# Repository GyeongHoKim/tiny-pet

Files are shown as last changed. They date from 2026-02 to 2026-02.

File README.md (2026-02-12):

# Tiny Pet

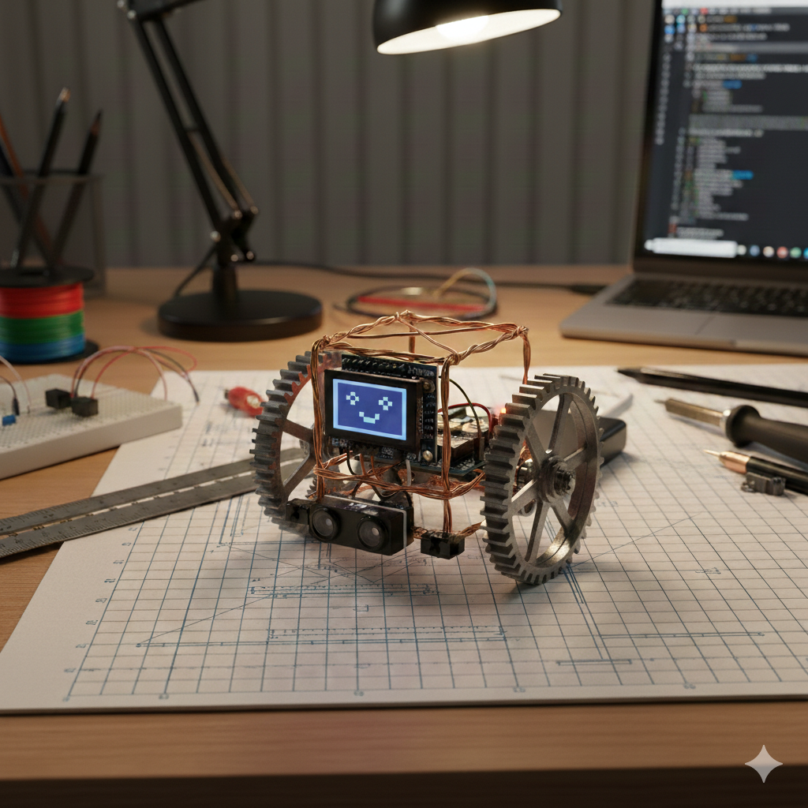
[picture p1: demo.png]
Demo


Small desk pet robot (TinyGo): random movement, obstacle avoidance (ultrasonic), edge avoidance (IR), OLED face expressions. Runs on Arduino Uno/Nano or STM32 Blue Pill.

## Requirements

- **Board:** Arduino Uno (`arduino`), Arduino Nano (`arduino-nano`), or STM32 Blue Pill (`bluepill`). Arduino: 5 V logic. Blue Pill: 3.3 V logic.
- **Software:** Go 1.20+, [TinyGo](https://tinygo.org/getting-started/install/). For Arduino: avrdude (used by TinyGo flash). For Blue Pill: [OpenOCD](http://openocd.org/) and ST-Link v2 programmer.

## Features

- **Random movement** — Drives forward and occasionally turns at random to wander on a flat surface.
- **Obstacle avoidance** — Ultrasonic sensor (HC-SR04) detects obstacles ahead; robot stops, reverses, then turns away. Threshold: `OBSTACLE_DISTANCE_THRESHOLD` in `sensors.go`.
- **Edge detection** — Two front IR sensors (A1–A2) detect desk edges; robot stops, reverses, and turns to avoid falling. Threshold: `EDGE_DETECTION_THRESHOLD` in `sensors.go`.
- **OLED face** — SSD1306 128x64 I2C OLED shows expressive faces: happy (moving), surprised (obstacle), scared (edge), excited (interacting), neutral (idle), with periodic blink animation.
- **Interaction (optional)** — Status LED (D13) and buzzer (D8) indicate current state (moving, avoiding obstacle, avoiding edge). Calibration on startup is indicated by LED blinks and beeps.

## Parts list

### Board

| Item | Note |
| --- | --- |
| Arduino Uno or Arduino Nano | Uno: target `arduino`. Nano: target `arduino-nano`. 5 V. |
| STM32 Blue Pill (STM32F103C8) | Target `bluepill`. 3.3 V. Low-cost option; requires ST-Link v2 to flash. |

### Required

| Component | Qty | Spec |
| --- | --- | --- |
| Mini L298N motor driver | 1 | H-bridge, 4 logic pins (IN1–IN4). ENA/ENB jumper → HIGH. Motor power from separate supply. |
| DC gear motors | 2 | 3–6 V DC gear motor (17–68 RPM range). |
| Steel gear 65T (wheels) | 2 | Press-fit on motor shaft, acts as wheel. |
| Copper wire frame | — | 1 mm (structural) + 0.7 mm (detail). Forms the body/chassis. |
| Ultrasonic distance sensor | 1 | HC-SR04 or compatible. Trig + Echo (digital). |
| IR sensors (analog) | 2 | Analog output to A1–A2 (front). Lower ADC = edge (e.g. TCRT5000-style). |
| SSD1306 OLED display | 1 | I2C (addr 0x3C). A4 (SDA), A5 (SCL). See **Recommended display** below. |
| Power supply (USB/adapter) | 1 | 5 V for Uno/Nano (USB or regulated adapter). Alternative: battery stack below. |
| 3.7V Li-ion battery (1S) | 1 | For battery operation (desk roaming). e.g. 18650, 14500, or pouch. |
| 1S protection module | 1 | Use with battery. Over-discharge/overcharge/short protection (B+/B-/P+/P-). |
| 5V boost converter | 1 | 3.x V → 5V (e.g. MT3608). Input/output capacitors recommended. |
| 5V→3.3V LDO (optional) | 1 | For Blue Pill or 3.3V peripherals (e.g. AMS1117-3.3). |

### Optional

| Component | Pin in code |
| --- | --- |
| Status LED | D13 (often built-in) |
| Buzzer | D8 (other leg GND) |
| MPU6050 (I2C) | SDA, SCL |
| Button | Free digital pin (not in current code) |

### Recommended display (fits 2KB SRAM)

**Use a 128×32 I2C OLED.** Firmware uses a 512-byte buffer; the face fills the screen.

| Product | Spec | Note |
| --- | --- | --- |
| [Adafruit 4440 – Monochrome 0.91" 128×32 I2C OLED](https://www.adafruit.com/product/4440) | 128×32, I2C 0x3C | STEMMA QT / Qwiic; 4-pin. ~$12.50. |
| Generic 0.91" 128×32 SSD1306 I2C | 128×32, I2C 0x3C | Many clones; ensure I2C (not SPI). |

We support Uno/Nano (2KB SRAM) only. If you use a 128×64 OLED on them, the face is drawn in the **top half** only.

## Wiring (Arduino pins)

```
D5, D4  → Mini L298N IN1, IN2 (left motor).  H-bridge: fwd/rev/stop.
D6, D9  → Mini L298N IN3, IN4 (right motor). ENA/ENB jumper → HIGH.
D7, A0  → Ultrasonic Trig, Echo (HC-SR04)
A1–A2   → IR edge sensors (analog, front only). Lower ADC = edge.
A4, A5  → SSD1306 OLED (I2C SDA, SCL). Hardware I2C on ATmega328P.
D13, D8 → Optional: LED, Buzzer
```

Pin constants: `hardware_arduino.go` (Uno/Nano) or `hardware_bluepill.go` (Blue Pill). Thresholds: `sensors.go` / `sensors_bluepill.go` (`OBSTACLE_DISTANCE_THRESHOLD`, `EDGE_DETECTION_THRESHOLD`).

## Wiring (STM32 Blue Pill)

```
PA8, PA9   → Mini L298N IN1, IN2 (left motor)
PA10, PA11 → Mini L298N IN3, IN4 (right motor)
PA12, PB10 → Ultrasonic Trig, Echo (HC-SR04). Avoid PA13/PA14 (SWD).
PA1, PA2   → IR edge sensors (ADC1, ADC2)
PB7, PB6   → SSD1306 OLED I2C SDA, SCL (I2C0)
PC13       → Status LED (onboard)
PB15       → Buzzer
```

Flash: connect ST-Link v2 to Blue Pill SWD (SWIO, SWCLK, 3V3, GND), then `make flash-bluepill`. Install OpenOCD (e.g. `brew install openocd`) if needed.

## Build & flash

Use the [Makefile](Makefile) for build, flash, format, and tests. Run `make help` for all targets.

| Command | Description |
| --- | --- |
| `make build` | Build for Blue Pill (default) → `firmware_bluepill.elf` |
| `make build-uno` | Build for Arduino Uno → `firmware.hex` |
| `make build-nano` | Build for Arduino Nano |
| `make flash` | Flash Uno to board (PORT auto-detected on macOS) |
| `make flash-nano` | Flash Nano to board |
| `make flash-bluepill` | Flash Blue Pill (ST-Link v2 + OpenOCD) |
| `make fmt` | Format Go code |
| `make tidy` | `go mod tidy` |
| `make test` | Run unit tests |
| `make run` | Run in emulator (no board) |
| `make clean` | Remove firmware artifacts |

Examples:

```bash
make build                    # Blue Pill (default)
make build-uno                # Uno
make build-nano flash-nano    # Nano: build then flash
make flash-bluepill           # Blue Pill (ST-Link v2 connected)
make flash PORT=/dev/cu.usbmodem14101   # macOS, set port explicitly
make flash PORT=COM3                    # Windows
```

### Firmware size (Arduino Uno/Nano 32KB flash)

The Makefile applies [TinyGo optimization flags](https://tinygo.org/docs/guides/optimizing-binaries/) (`-scheduler=none`, `-gc=leaking`). Calibration `println` output is gated by a `debug` build tag so release builds use a no-op and save space. The firmware may still slightly exceed 32KB on Uno/Nano; if the build reports overflow, you can build with `-tags=debug` for development (serial output) or consider a board with more flash.

## Run

Wire → power 5 V → flash. On startup: short calibration (LED/beep). Then it wanders and avoids obstacles/edges.

## Development

### Project layout

| Path | Description |
| --- | --- |
| `main.go` | Entry point, main loop, module wiring |
| `hardware_arduino.go` / `hardware_bluepill.go` | Pin constants, `Motor`, `Robot`, board init (build tag selects) |
| `motors.go` | `MotorController` — direction, speed, timed moves |
| `sensors.go` / `sensors_bluepill.go` | `SensorModule` — ultrasonic, IR, thresholds (Blue Pill uses time-based ultrasonic) |
| `navigation.go` | `NavigationModule` — state machine, behavior mode |
| `behaviors.go` | `BehaviorPatterns` — LED and buzzer feedback |
| `display.go` | `DisplayModule` — SSD1306 OLED face expressions |
| `faces.go` | Procedural face drawing (helpers + 6 expressions) |
| `calibration.go` | `CalibrationModule` — sensor/motor calibration |
| `internal/navlogic/` | Pure state logic (no hardware); unit-testable |

### Emulator (no board)

Run firmware under simavr to check that the program starts and the main loop runs. Sensor and motor I/O are simulated (default values), so behavior will not match real hardware.

```bash
# macOS: simavr is in the osx-cross/avr tap (not in default Homebrew)
brew tap osx-cross/avr
brew install simavr
make run
```

### Unit tests

Navigation state logic only (sensor inputs → next state). Uses the standard Go toolchain; no TinyGo or board needed.

```bash
make test
```

### Tuning

- Obstacle/edge thresholds: `sensors.go` or `sensors_bluepill.go` (`OBSTACLE_DISTANCE_THRESHOLD`, `EDGE_DETECTION_THRESHOLD`).
- Avoidance timings: `navigation.go`. Runtime adjustment via `CalibrationModule.AdjustThresholds()`.
- Blue Pill: if ultrasonic distance is wrong, adjust `bluepillLoopsPerMicrosecond` in `sensors_bluepill.go`.

## License

MIT. See [LICENSE](LICENSE).

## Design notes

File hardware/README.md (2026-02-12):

# Tiny Pet — Hardware (Power Supply)

KiCad project for the **3.7V Li-ion battery power supply** used when running the desk pet on battery (no USB cable).

## Block diagram

```
3.7V Li-ion 1S → Protection (1S) → Boost (3.x V → 5V) → 5V rail → [optional] LDO → 3.3V rail
                    (B+/B-/P+/P-)        (e.g. MT3608)      (J3)       (e.g. AMS1117-3.3)   (J4)
```

- **5V rail (J3):** Arduino Uno/Nano, L298N logic (VSS) and motor (VM), HC-SR04, 5V-type SSD1306. Connect to board 5V/GND or USB replacement.
- **3.3V rail (J4, optional):** Blue Pill, 3.3V OLED/IR. Fed from 5V via LDO so sensors see stable voltage even when the battery sags.

## KiCad project

| File | Description |
|---|---|
| `tiny-pet-power.kicad_pro` | KiCad 7/8/9 project |
| `tiny-pet-power.kicad_sch` | Schematic: J1 Battery, J2 Protection out, J3 5V out, J4 3.3V out |
| `tiny-pet-power.kicad_pcb` | PCB (minimal outline; place boost/LDO and connectors as needed) |

Open `tiny-pet-power.kicad_pro` in KiCad to edit the schematic or PCB. The schematic uses only KiCad built-in symbols (Connector_Generic:Conn_01x02, power:VCC, power:GND).

Use only KiCad default (global) symbol library table; do not add a project-specific table. If symbols show as ??, set up the global table in **Preferences → Manage Symbol Libraries** (e.g. from KiCad default template).

## Verification

- **Project structure:** `mcp_kicad_validate_project` with `project_path`: `hardware/tiny-pet-power.kicad_pro` (or full path).
- **PCB DRC:** From repo root,  
  `kicad-cli pcb drc hardware/tiny-pet-power.kicad_pcb`  
  (or use KiCad MCP `run_drc_check` with the same project path).
- **Schematic ERC:** Run ERC from KiCad GUI (Schematic Editor → Inspect → Electrical Rules Check). CLI `kicad-cli sch erc` may require the same library setup as the GUI.

## Parts

Battery power uses the same items as the main [README](../README.md) Parts list: 3.7V Li-ion 1S, 1S protection module, 5V boost converter, and optionally 5V→3.3V LDO. Input/output capacitors and connectors (e.g. JST-PH for battery) as needed.

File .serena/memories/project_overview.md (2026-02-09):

# Tiny Pet - Project Overview

## Purpose
TinyGo-based desk pet robot firmware for Arduino Uno/Nano and STM32 Blue Pill. Wandering robot with obstacle avoidance (ultrasonic), edge detection (IR), and OLED face expressions.

## Tech Stack
- **Language:** Go (TinyGo)
- **Targets:** Arduino Uno / Arduino Nano (32KB flash, 2KB SRAM, 5V); STM32 Blue Pill (STM32F103C8, 64KB+ flash, 20KB SRAM, 3.3V). Build tag `bluepill` selects Blue Pill; default is Arduino.
- **Dependencies:** tinygo.org/x/drivers v0.27.0 (SSD1306 OLED)
- **Build:** Make + TinyGo. Blue Pill flash: ST-Link v2 + OpenOCD.

## Code Structure
| File | Role |
|---|---|
| main.go | Entry point, main loop |
| hardware_arduino.go / hardware_bluepill.go | Pin constants, Motor, Robot (build tag selects; all `machine` imports here) |
| motors.go | MotorController — differential drive |
| sensors.go / sensors_bluepill.go | SensorModule — ultrasonic, IR (Blue Pill uses time-based ultrasonic) |
| navigation.go | NavigationModule — state machine |
| behaviors.go | BehaviorPatterns — LED/buzzer |
| display.go | DisplayModule — SSD1306 OLED |
| faces.go | Procedural face drawing |
| calibration.go | CalibrationModule |
| internal/navlogic/ | Pure state logic, unit-testable with standard Go |

## Hardware (see README for full wiring)
- Arduino: motors D4–D9, ultrasonic D7/A0, IR A1–A2, I2C A4/A5, LED D13, buzzer D8.
- Blue Pill: motors PA8–PA11, ultrasonic PA12/PB10, IR PA1/PA2, I2C PB7/PB6, LED PC13, buzzer PB15.

## Key Constraints
- Uno/Nano: 32KB flash, 2KB SRAM (Makefile: -scheduler=none -gc=leaking). Blue Pill has more headroom.
- 128x32 OLED = 512-byte buffer. Debug output gated by build tag `debug`.

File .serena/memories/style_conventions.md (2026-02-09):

# Code Style & Conventions

- **Language:** Go with TinyGo constraints
- **Naming:** UPPER_SNAKE for constants, CamelCase for types/exported, camelCase for unexported
- **Comments:** Minimal. Only essential GODoc (e.g. conversion semantics, non-obvious types). No redundant inline comments. Project description and usage live in README.md.
- **Modules:** Each hardware subsystem in its own file with a struct (MotorController, SensorModule, etc.). Board-specific code: build tags (`bluepill` / `!bluepill`) in hardware_*.go and sensors_*.go.
- **Hardware isolation:** All `machine` imports in hardware-touching files only
- **Testability:** Pure logic in internal/navlogic/ — standard Go tests, no TinyGo
- **Debug:** debugPrint() gated by build tag (debug_debug.go vs debug_release.go)
- **Motor control:** Digital HIGH/LOW via L298N (no PWM). Differential drive.

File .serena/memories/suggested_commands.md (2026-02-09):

# Suggested Commands

## Build
- `make build` — Arduino Uno → firmware.hex
- `make build-nano` — Arduino Nano
- `make build-bluepill` — STM32 Blue Pill → firmware_bluepill.elf

## Flash
- `make flash` — Flash Uno (port auto-detected on macOS)
- `make flash-nano` — Flash Nano
- `make flash-bluepill` — Flash Blue Pill (ST-Link v2 + OpenOCD)
- `make flash PORT=/dev/cu.usbmodem14101` — Explicit port (Arduino)

## Development
- `make fmt` — Format Go (go fmt + gofmt -s -w)
- `make tidy` — go mod tidy
- `make test` — Unit tests (internal/navlogic only, standard Go)
- `make run` — simavr emulator (no board)
- `make clean` — Remove firmware.hex, firmware_bluepill.elf

## Task completion
1. `make fmt`
2. `make build` or `make build-bluepill` as needed
3. `make test`

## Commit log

2026-02-07 feat(hardware): add pin constants and robot hardware init
    Define all Arduino pin constants for motors (D5, D6), ultrasonic
    HC-SR04 (D7, A0), IR edge sensors (A1–A4), and optional LED/buzzer
    (D13, D8). Introduce Motor type with SetSpeed/Stop and Robot struct
    that owns motors, sensors, and status pins with Initialize(), BlinkLED(),
    and Beep() for startup and calibration feedback.
2026-02-07 feat(motors): add motor controller and timed movement primitives
    MotorController drives left/right motors with direction constants
    (MOVE_FORWARD, TURN_LEFT, etc.) and speed levels. Exposes Stop(),
    MoveForward(), MoveBackward(), TurnLeft(), TurnRight() and timed
    primitives (MoveForwardFor, TurnLeftFor, etc.) used by navigation and
    calibration. MoveRandomly() picks a random direction for wandering
    behavior.
2026-02-07 feat(sensors): add sensor module for ultrasonic and IR readings
    SensorModule wraps HC-SR04 (ReadUltrasonicDistance in cm, timeout
    handling) and four analog IR sensors (ReadIRSensors). Defines
    OBSTACLE_DISTANCE_THRESHOLD and EDGE_DETECTION_THRESHOLD. Exposes
    IsObstacleDetected() and IsEdgeDetected() for the navigation state
    machine.
2026-02-07 feat(navlogic): add pure navigation state transition logic
    Package navlogic has no machine/hardware dependency so it can be
    tested with the standard Go toolchain. Defines state constants
    (Idle, Moving, ObstacleAvoidance, EdgeAvoidance, Interacting) and
    NextStateFromSensors(currentState, obstacleDetected, edgeDetected)
    for sensor-driven transitions from Idle/Moving; edge takes precedence
    over obstacle when both are detected.
2026-02-07 test(navlogic): add unit tests for sensor-driven state transitions
    Test NextStateFromSensors for Idle and Moving: all four combinations
    of obstacle/edge (edge precedence when both true). Assert that
    ObstacleAvoidance, EdgeAvoidance, and Interacting states are left
    unchanged by sensor input so that physical actions in main can drive
    transitions.
2026-02-07 feat(navigation): add navigation module and state machine
    NavigationModule ties MotorController and SensorModule to navlogic:
    reads sensors, calls NextStateFromSensors, and runs obstacle/edge
    avoidance sequences (stop, reverse, turn). Supports RANDOM_WALK_MODE
    with random turns; keeps obstacle/edge counts. Update() drives the
    state machine; avoidance states transition back to Moving after
    timed motor actions. GetStateName() for behavior feedback.
2026-02-07 feat(behaviors): add LED and buzzer feedback patterns
    BehaviorPatterns drives status LED (D13) and buzzer (D8). IndicateStateChange()
    shows short patterns per state (MOVING, AVOIDING OBSTACLE, AVOIDING EDGE,
    INTERACTING). PlayTone() and HeartbeatPattern() provide periodic feedback
    without blocking the main loop. Used for calibration and runtime state
    indication.
2026-02-07 feat(calibration): add sensor and motor calibration module
    CalibrationModule runs CalibrateSensors() (ultrasonic baseline and IR
    readings with LED/beep feedback) and CalibrateMotors() (short forward/
    turn test). CalibrateComplete() runs both at startup. AdjustThresholds()
    allows runtime tuning of obstacle/edge thresholds used by SensorModule.
2026-02-07 feat(main): add entry point and main loop with module wiring
    Initialize Robot, SensorModule, MotorController, NavigationModule,
    BehaviorPatterns, and CalibrationModule. Run CalibrateComplete() then
    enter main loop: NavigationModule.Update(), state-change LED/buzzer
    feedback via BehaviorPatterns, optional heartbeat, and 100ms delay to
    avoid overwhelming the MCU.
2026-02-07 docs: add README with build, wiring, and project layout
    Describe Tiny Pet: desk robot (TinyGo) with random movement, ultrasonic
    obstacle avoidance, and IR edge avoidance for Arduino Uno/Nano.
    Include requirements, parts list, pin wiring (D5/D6, D7/A0, A1–A4,
    D13/D8), build and flash commands (tinygo build/flash), emulator
    (simavr) and unit test instructions, and project layout table
    mapping paths to modules (main, hardware, motors, sensors, navigation,
    behaviors, calibration, internal/navlogic).
2026-02-07 feat(debug): add debug build tag for optional serial output
    - debug_debug.go: debugPrint calls println when built with -tags=debug
    - debug_release.go: debugPrint is no-op in default release builds to save flash
    - Calibration and development can use -tags=debug for serial feedback without bloating production firmware
2026-02-07 refactor(hardware): centralize pin constants and add IR sensor indices
    - Use machine.ADC0..ADC4 for analog pins (TinyGo A0–A4) instead of machine.A0–A4
    - Add IR_FRONT_LEFT, IR_FRONT_RIGHT, IR_REAR_LEFT, IR_REAR_RIGHT, IR_SENSOR_COUNT for index-based loops
    - Normalize pin constant names and trim comments for clarity
2026-02-07 refactor(sensors): use navlogic distance helpers and simplify readings
    - Use navlogic.EchoCountToDistanceCm and navlogic.IsWithinThreshold for ultrasonic logic
    - Simplify IR edge detection with index-based loop using hardware.IR_SENSOR_COUNT
    - Reduce duplication and keep sensor logic aligned with testable navlogic package
2026-02-07 refactor(motors): simplify motor API and implementation
    - Streamline motor control methods and remove redundant code
    - Align with centralized hardware pin and Robot structure
2026-02-07 refactor(calibration): use debugPrint and simplify calibration flow
    - Replace println with debugPrint so calibration output is gated by -tags=debug
    - Reduces release firmware size while keeping serial output for development
    - Simplify calibration steps and structure
2026-02-07 refactor(main): simplify setup and main loop wiring
    - Cleaner Robot initialization and module wiring (sensors, motors, navigation, behaviors, calibration)
    - Main loop uses navigation state machine and behavior patterns without redundant logic
    - Align with refactored hardware, navlogic, and debug build tag
2026-02-07 refactor(hardware): reduce IR sensors from 4 to 2 and add I2C display pins
    Remove rear IR sensors (A3, A4) to free up A4/A5 for the I2C OLED
    display.
    Only front-left (A1) and front-right (A2) IR sensors are retained, as
    the
    robot primarily moves forward and rear edge detection is less critical.
2026-02-07 feat(deps): add tinygo.org/x/drivers v0.27.0 for SSD1306 OLED support
    Use v0.27.0 specifically because v0.34.0 breaks on AVR targets —
    ssd1306_spi.go imports internal/legacy which references
    machine.PinInputPulldown, undefined on ATmega328P.
2026-02-07 feat(display): add OLED face expressions and display module
    faces.go: procedural pixel-art rendering with 4 drawing helpers
    (setHLine, setFillRect, setFillCircle, setCircle) and 6 face functions
    (neutral, happy, surprised, scared, excited, blink). No bitmap data or
    heap allocation — all shapes drawn via SetPixel calls.
    display.go: DisplayModule wraps SSD1306 I2C driver with
    state-to-expression
    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
2026-02-07 feat(main): integrate OLED display into startup and main loop
    Initialize I2C0 at 400 KHz, create DisplayModule, show happy face on
    startup. On each state change, update the face expression alongside the
    existing LED indicator. Call UpdateAnimation() every loop tick for
    periodic eye blink animation.
2026-02-07 docs: update README and AGENTS.md for OLED display and 2-sensor config
    Reflect IR sensor reduction (4→2 front-only), add SSD1306 OLED to parts
    list and wiring section, document new display.go/faces.go in project
    layout, and update pin map and module diagram in AGENTS.md.
2026-02-09 fix(sram): shrink display size into 32
    - because Arduino Uno/Nano has low sized SRAM, we cannot use 128x64
    - shrink height into 32
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2026-02-12 docs: update power
    - 3.7v battery
    [tiny-pet-power.kicad_pcb, tiny-pet-power.kicad_sch]
